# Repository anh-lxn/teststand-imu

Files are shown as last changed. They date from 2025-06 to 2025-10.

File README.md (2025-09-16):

# IMU Calibration Test Stand with Differential Gear System

## Project Overview

This project presents the design and function of a **two-axis IMU calibration test stand**, developed to calibrate inertial measurement units (IMUs) such as the [MPU6050](https://invensense.tdk.com/products/motion-tracking/6-axis/mpu-6050/). The test stand enables controlled, repeatable motion for precise sensor calibration.

All mechanical parts are **3D printed**, and motion is driven by **NEMA 17 stepper motors** in combination with an **HTD timing belt system**. The movement is realized through a **differential gear mechanism**, providing two degrees of freedom (DoF).

---

## ⚙️ System Characteristics

- 🎯 **Purpose**: Accurate calibration of IMUs
- 🧩 **Mechanics**: Differential gear-driven motion
- 🖨️ Manufacturing: Fully 3D printed components
- 🔄 **Degrees of Freedom**:  
  - **Z-axis**: Independently rotatable  
  - **X and Y axes**: Coupled motion, dependent on Z-axis rotation
- 🚀 **Actuation**: NEMA 17 stepper motors with HTD belt drive
- 🧠 **Controller**: Arduino Nano for motor control and signal processing

---

## 🖼️ Visualizations

<b>Z-Axis Rotation</b> &nbsp;&nbsp;&nbsp;&nbsp;&nbsp;&nbsp;&nbsp;&nbsp;&nbsp;&nbsp;&nbsp;&nbsp;&nbsp;&nbsp;&nbsp;&nbsp;&nbsp;&nbsp;&nbsp;&nbsp;&nbsp;&nbsp;&nbsp;&nbsp;&nbsp;&nbsp;&nbsp;&nbsp;&nbsp;&nbsp;&nbsp;&nbsp;&nbsp;&nbsp;&nbsp;&nbsp;&nbsp;&nbsp;&nbsp;&nbsp;&nbsp;&nbsp;&nbsp;&nbsp;&nbsp;&nbsp;&nbsp;&nbsp;&nbsp;&nbsp;&nbsp;&nbsp;&nbsp;&nbsp;&nbsp;&nbsp;&nbsp;&nbsp;&nbsp;&nbsp;&nbsp;&nbsp;&nbsp;&nbsp;&nbsp;&nbsp;&nbsp;&nbsp;&nbsp;&nbsp;&nbsp;&nbsp;&nbsp;&nbsp;&nbsp;&nbsp;&nbsp; <b>X/Y-Axis Rotation</b><br>
 

<b>Exploded Assembly View</b><br>
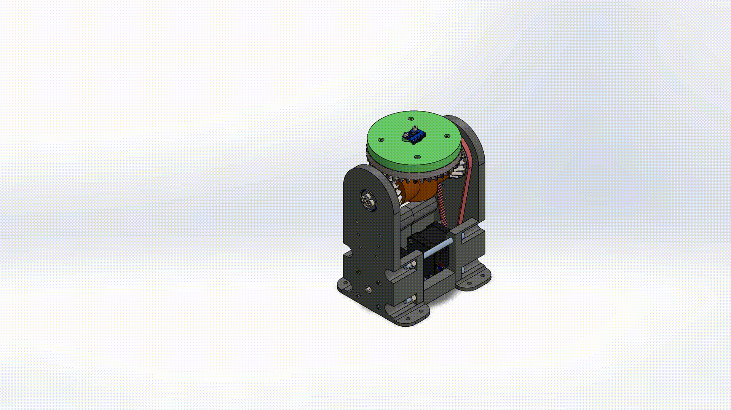
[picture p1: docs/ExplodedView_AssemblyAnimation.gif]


---

## 🛠️ Calibration in Real Life (HAS TO BE ADDED!!!)

<p align="center">
  
</p>

This animation demonstrates the real-life calibration process, where the IMU undergoes controlled multi-axis rotations.  
It shows how the test stand executes repeatable motion sequences to allow for accurate sensor calibration.

---
## Wiring Diagram

<p align="center">
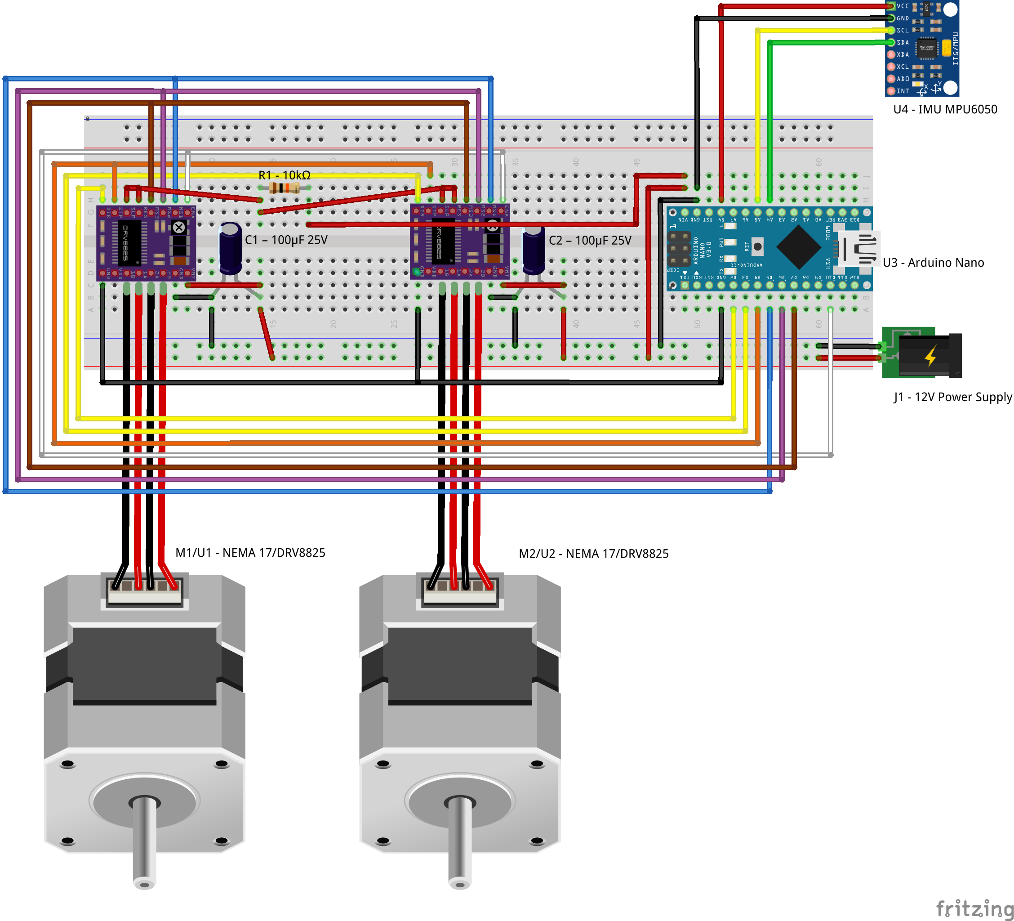
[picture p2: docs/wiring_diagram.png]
  
</p>

The wiring diagram shows the connection between the Arduino Nano, stepper motor drivers (A4988/DRV8825), NEMA 17 stepper motors, the MPU6050 sensor, and power supply.

---

## 📊 Sensor Data Visualization

To validate the calibration process, both **accelerometer** and **gyroscope** signals were recorded before and after calibration.  
The plots show the comparison between **raw data**, **calibrated data**, and the **expected values** during controlled rotations.  

### 📈 Accelerometer Calibration
<p align="center">
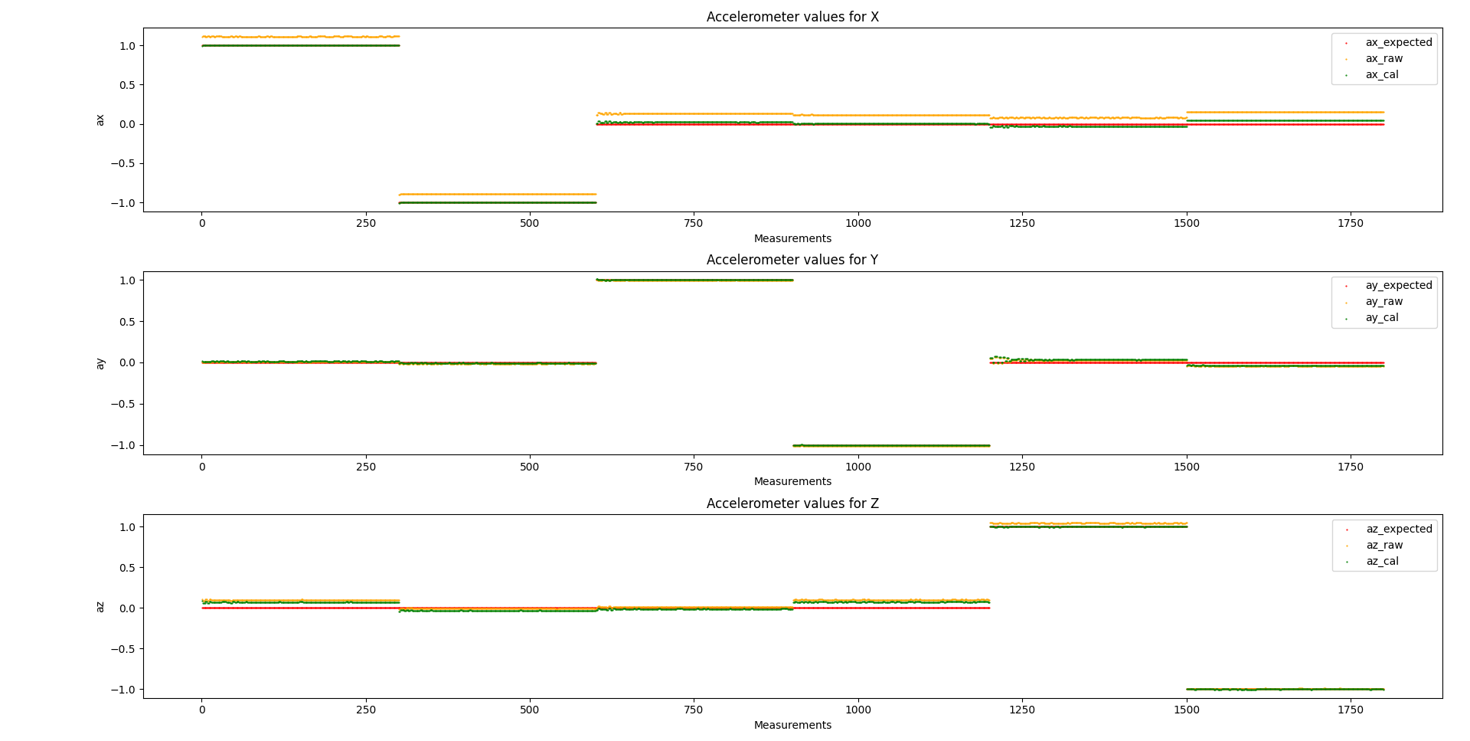
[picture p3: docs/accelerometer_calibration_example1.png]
  
</p>

The accelerometer plots illustrate the three axes (**ax, ay, az**).  
- 🟠 *Raw data* (uncalibrated)  
- 🟢 *Calibrated data* (after bias and scale factor correction)  
- 🔴 *Expected values* (reference for controlled rotation)  

Calibration significantly reduces **bias** and aligns the output closer to the expected reference.  

---

### 📈 Gyroscope Calibration
<p align="center">
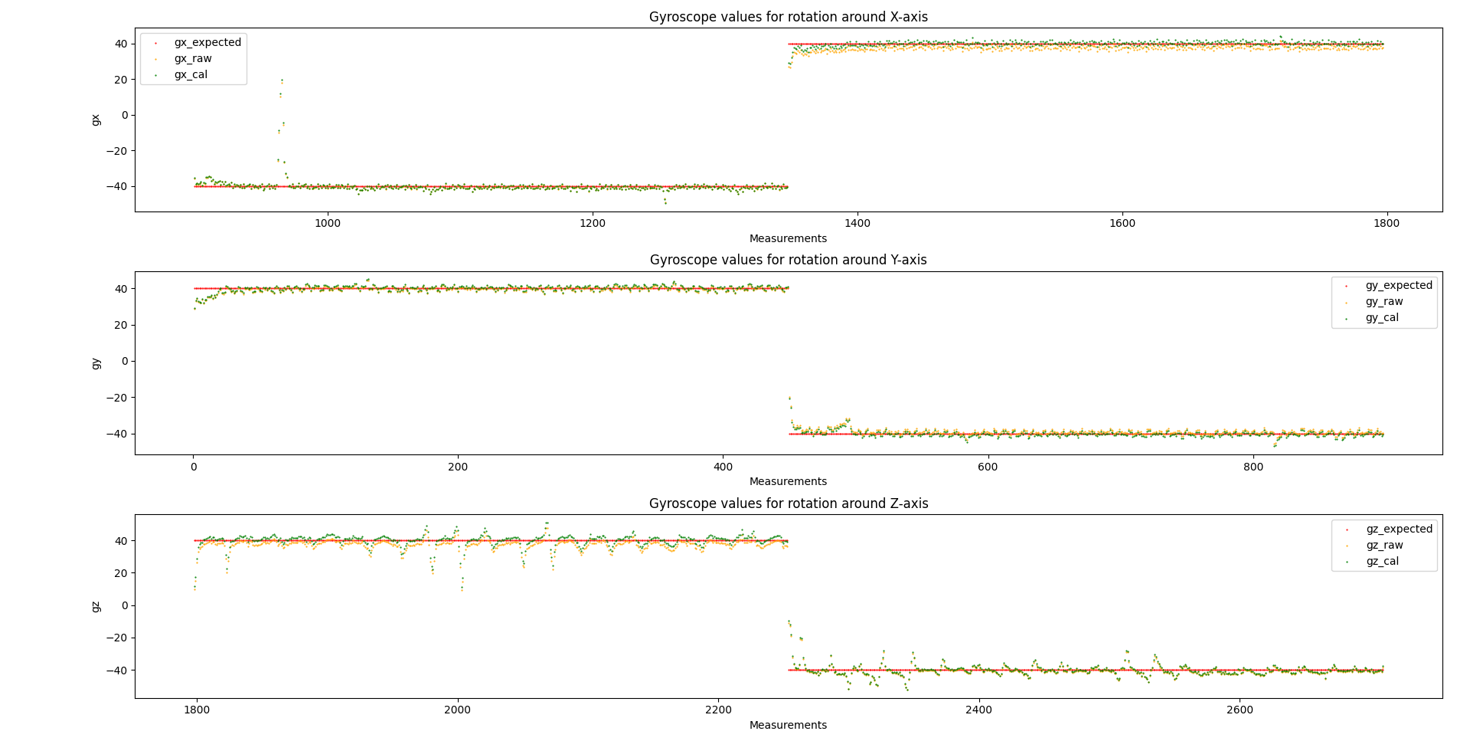
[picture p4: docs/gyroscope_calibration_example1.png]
  
</p>

The gyroscope plots illustrate the three axes (**gx, gy, gz**).  
- 🟠 *Raw data* (uncalibrated)  
- 🟢 *Calibrated data* (after correction)  
- 🔴 *Expected values* (reference for applied rotation)  

Calibration minimizes **offset drift** and ensures a more accurate representation of angular velocity.  

---

✅ These visualizations confirm that the test stand enables **reliable calibration** by applying repeatable motion sequences and comparing sensor output to ground truth.

## 🧠 Motivation

Reliable IMU data is only possible when the sensors are properly **calibrated**. This test stand allows for controlled motion sequences, helping to identify and compensate for common issues such as drift, offset, and axis misalignment.

---

## 🚀 Project Status & Outlook

✅ The hardware and mechanics of the calibration test stand are complete.
🔜 Future work will focus on:

- 📈 Further data processing
- 💻 Graphical user interface (GUI) for easy operation

---

## 👨‍🔧 Author

- Anh Le Xuan – Student Assistant (SHK), responsible for mechanical design and implementation  
- Benjamin Waschilewski – Research Associate and Supervisor  
- Institute of Textile Machinery and High Performance Material Technology (ITM), TU Dresden

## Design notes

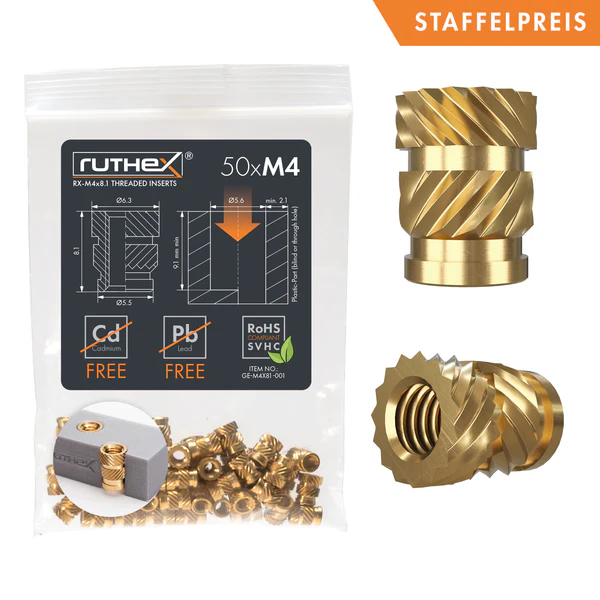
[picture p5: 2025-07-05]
docs/M4x6.3x8.1(M4xDxL).jpg

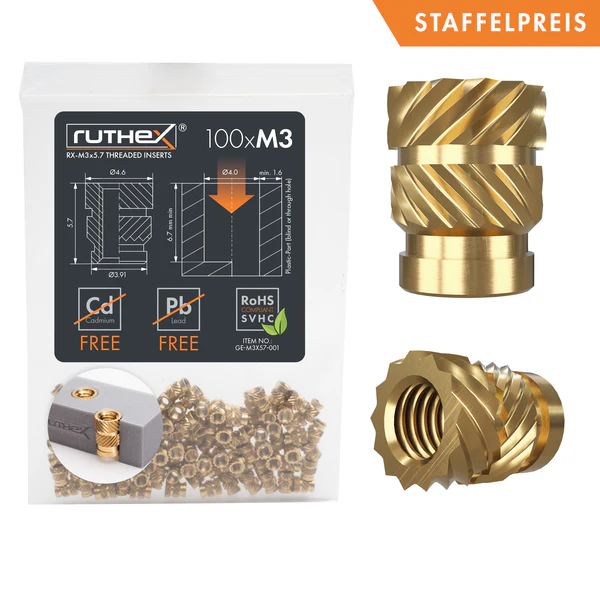
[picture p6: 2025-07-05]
docs/M3x4.6x5.7(M3xDxL).jpg

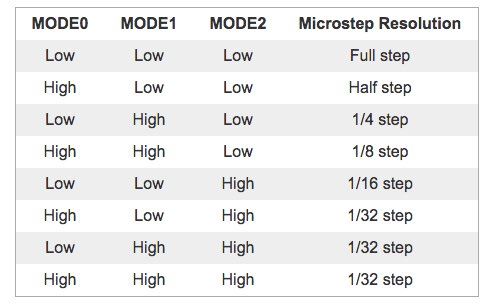
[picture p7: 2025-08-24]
docs/DRV8825_MicrosteppingModes.jpeg

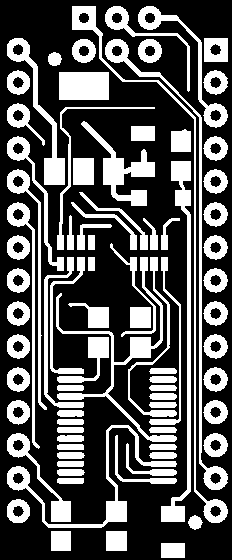
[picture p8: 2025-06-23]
cad/Version_2_neu(Differentialgetriebe)/Elektronik/arduino nano/nanobot_maskm.bmp

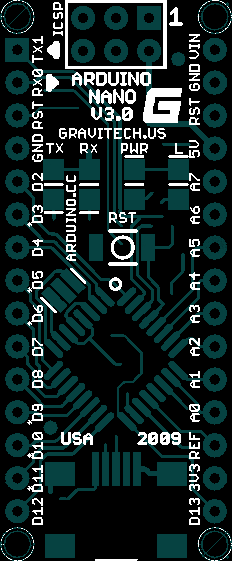
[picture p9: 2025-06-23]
cad/Version_2_neu(Differentialgetriebe)/Elektronik/arduino nano/nanoblack.bmp

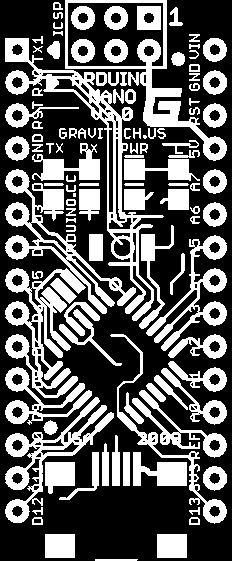
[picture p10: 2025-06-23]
cad/Version_2_neu(Differentialgetriebe)/Elektronik/arduino nano/nanoblack_mask.bmp

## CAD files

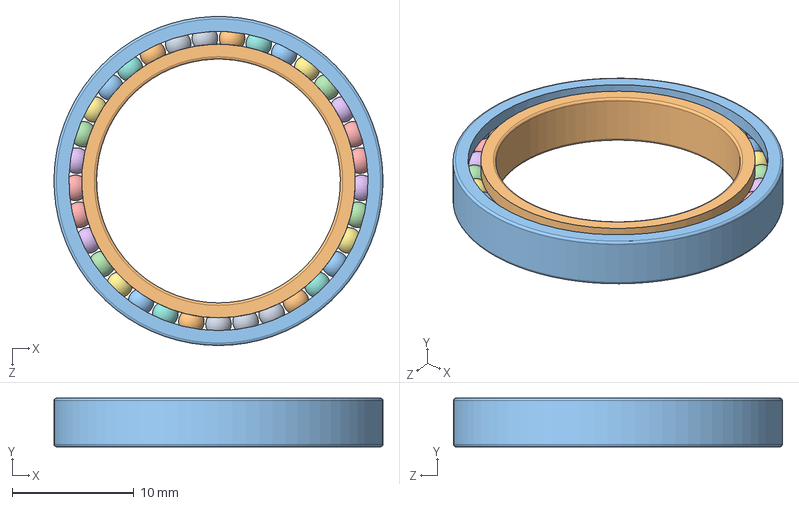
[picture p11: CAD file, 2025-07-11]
cad/Version_2_neu(Differentialgetriebe)/Radialrillenkugellager 6704 20x27x4/Radialrillenkugellager 6704 20x27x4.SLDASM
27.0 x 4.00 x 27.0 mm

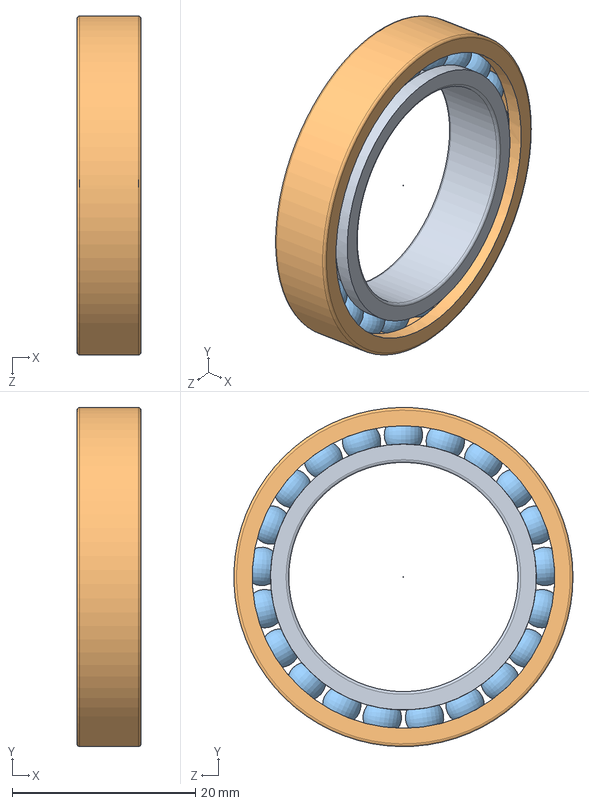
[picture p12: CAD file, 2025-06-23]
cad/Version_2_neu(Differentialgetriebe)/Kegelrad/Radialrillenkugellager 6805 25x37x7/Radialrillenkugellager 6805 25x37x7.SLDASM
7.00 x 37.0 x 37.0 mm
bearing_6805_01
bearing_6805_02
bearing_6805_03

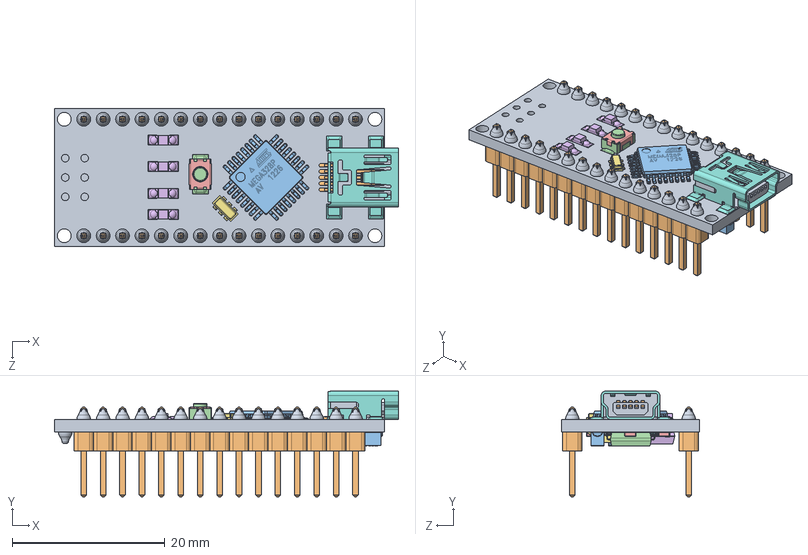
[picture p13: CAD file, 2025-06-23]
cad/Version_2_neu(Differentialgetriebe)/Pack and Go/arduino nano.SLDASM
45.0 x 13.9 x 18.0 mm
nano-board
15pin_header__ x 2
atmega328
ftdi FT232rl
smt_resistor222 x 5
led x 4
16mhz crystal - measured
MINIUSBSHELL
MINIUSBCORE
MINI USB CONTACT x 5
cap106C x 2
reset core
reset shell
nano - reg
NANO DIODE
189 RESISTOR PACK
102 RESISTOR PACK

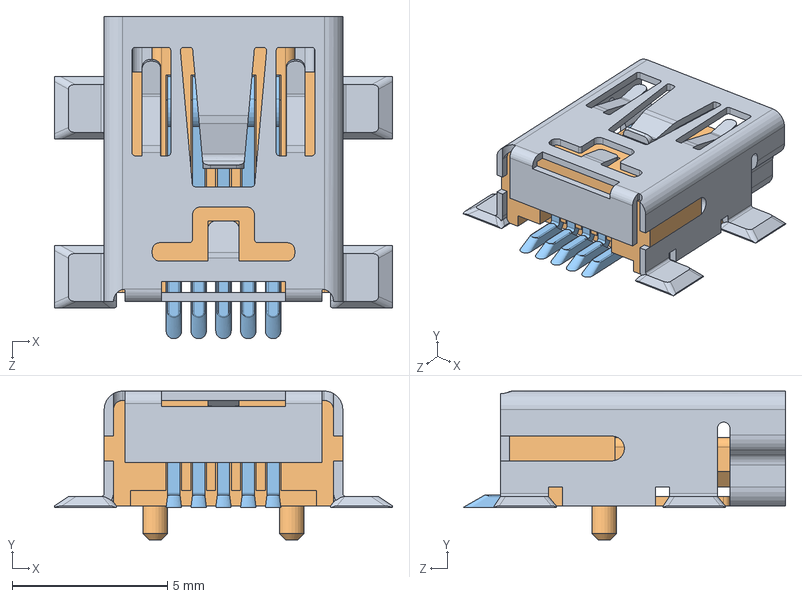
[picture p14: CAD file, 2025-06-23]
cad/Version_2_neu(Differentialgetriebe)/Pack and Go/MINIUSB - MEASURED.SLDASM
10.9 x 4.80 x 10.4 mm
MINIUSBSHELL
MINIUSBCORE
MINI USB CONTACT x 5

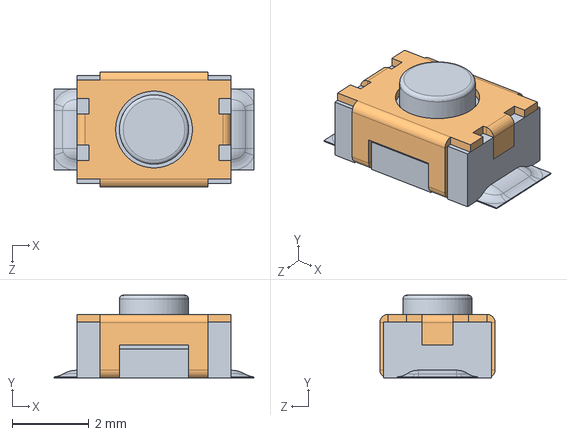
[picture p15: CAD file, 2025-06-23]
cad/Version_2_neu(Differentialgetriebe)/Pack and Go/reset button.SLDASM
5.20 x 2.15 x 3.00 mm
reset core
reset shell

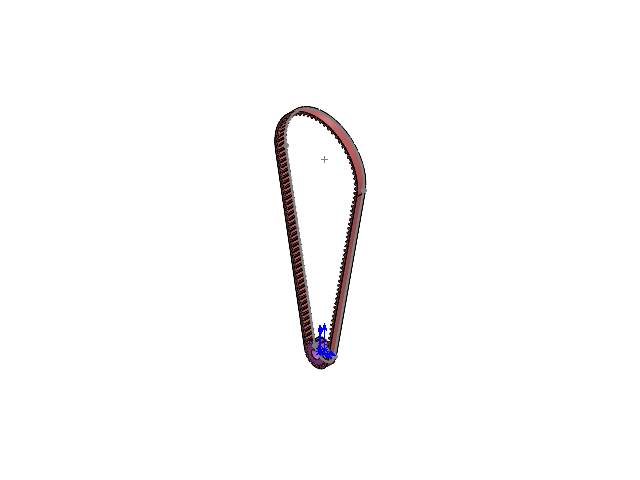
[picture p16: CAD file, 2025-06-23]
cad/Version_2_neu(Differentialgetriebe)/Motorantrieb/Motorantrieb.SLDASM
Motorantrieb_Zahnriemen
Riemen3-4

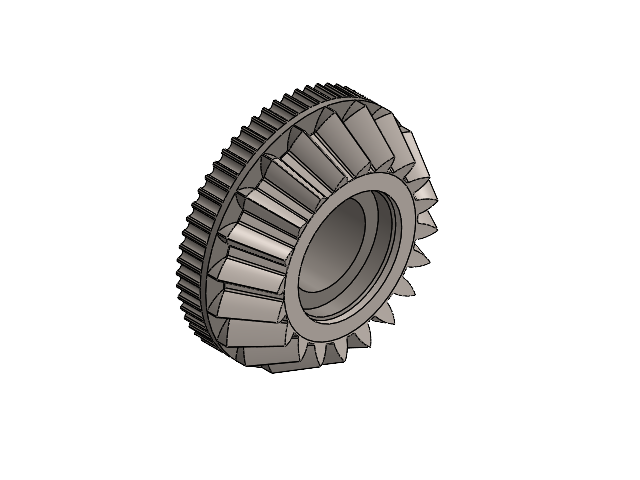
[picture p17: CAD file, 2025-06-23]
cad/Version_2_neu(Differentialgetriebe)/Pack and Go/Ritzel.SLDASM
Zahnraderweiterung
straight bevel pinion_iso

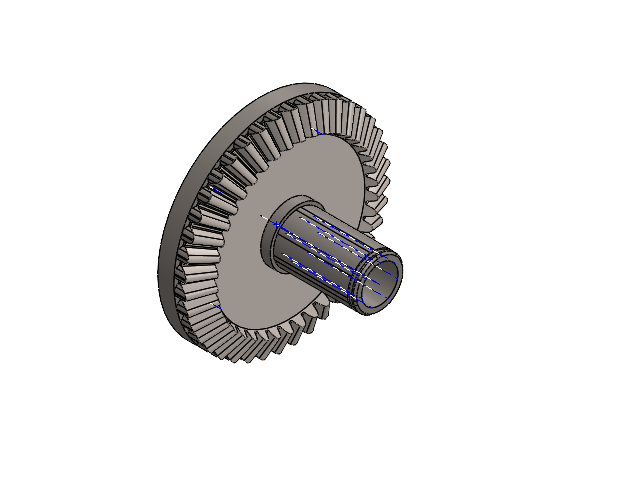
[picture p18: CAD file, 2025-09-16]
cad/Version_2_neu(Differentialgetriebe)/Kegelrad/Kegelrad.SLDASM
Kegelrad_Custom
Zahnraderweiterung Kegelrad

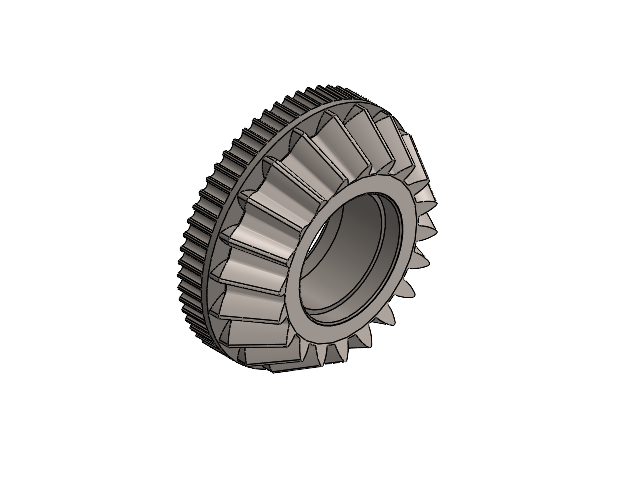
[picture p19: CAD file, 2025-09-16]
cad/Version_2_neu(Differentialgetriebe)/Ritzel/Ritzel.SLDASM
Zahnraderweiterung
Ritzel_Custom

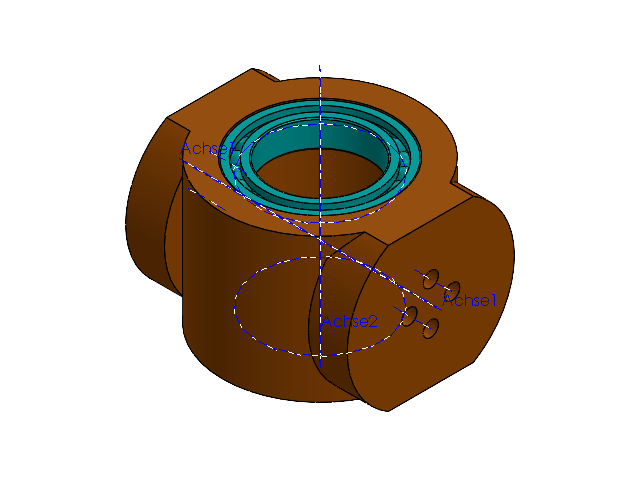
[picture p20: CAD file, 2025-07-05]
cad/Version_2_neu(Differentialgetriebe)/Kegelrad/Getriebehub_Baugruppe.SLDASM
Getriebehub
bearing_6805_01 x 2
bearing_6805_02 x 2
bearing_6805_03 x 2

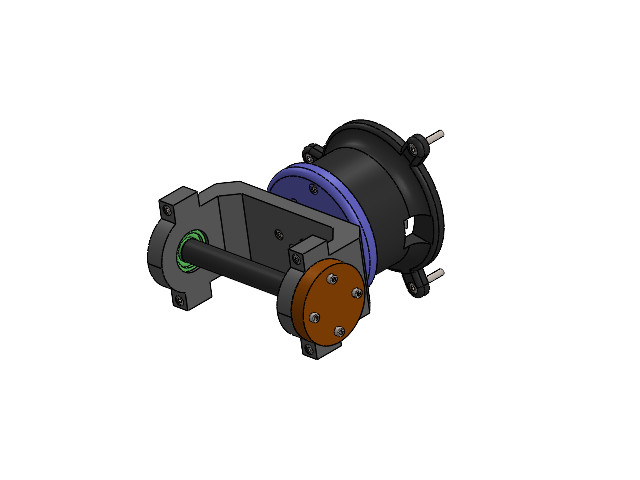
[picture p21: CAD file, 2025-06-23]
cad/Version_1_alt/IMU-Teststand.SLDASM
Schrittmotor z-Achse
socket head cap screw 4762_din x 14
Unteres Gehäuse
Gewindeeinsatz M3xL4xD4 x 7
Deckel für unteres Gehäuse
radial ball bearing_68_din x 3
Welle
circlip for shafts normal_din x 2
Deckel Festlager
Gewindeeinsatz M3xL6xD4 x 4
socket head cap screw_iso x 8
U-förmiger Gimbal Rahmen - Unteres Teil
Verbindung Motor mit U-Gimbal
hex nut style 1 gradeab_iso x 4

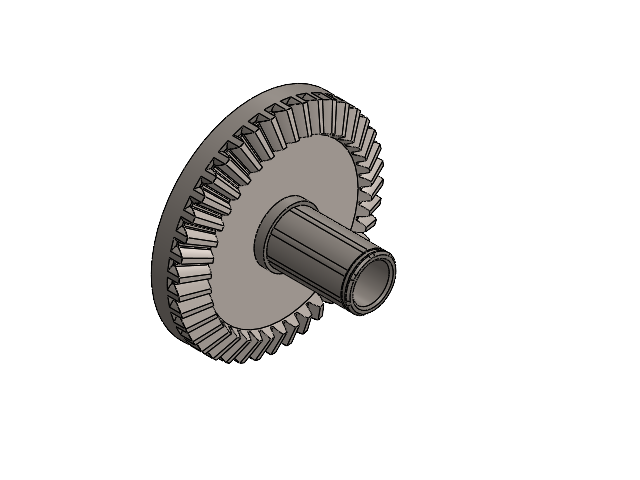
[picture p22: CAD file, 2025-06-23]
cad/Version_2_neu(Differentialgetriebe)/Pack and Go/Kegelrad.SLDASM
straight bevel gear_iso
Zahnraderweiterung Kegelrad

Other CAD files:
cad/Version_2_neu(Differentialgetriebe)/Pack and Go/Getriebehub_Baugruppe.SLDASM
cad/Version_2_neu(Differentialgetriebe)/Pack and Go/Radialrillenkugellager 6704 20x27x4.SLDASM
cad/Version_2_neu(Differentialgetriebe)/Pack and Go/Radialrillenkugellager 6805 25x37x7.SLDASM
cad/Version_2_neu(Differentialgetriebe)/Elektronik/arduino nano/MINIUSB - MEASURED.SLDASM
cad/Version_2_neu(Differentialgetriebe)/Elektronik/arduino nano/reset button.SLDASM
cad/Version_2_neu(Differentialgetriebe)/Elektronik/arduino nano/arduino nano.SLDASM
cad/Version_1_alt/Deckel Festlager.SLDPRT
cad/Version_1_alt/Deckel für unteres Gehäuse.SLDPRT
cad/Version_1_alt/Gewindeeinsatz M3xL4xD4.SLDPRT
cad/Version_1_alt/Gewindeeinsatz M3xL6xD4.SLDPRT
cad/Version_1_alt/Kugellager Deckel DIN 625 - 6000.SLDPRT
cad/Version_1_alt/Motoren/Schrittmotor z-Achse.SLDPRT
cad/Version_1_alt/U-förmiger Gimbal Rahmen - Oberes Teil.SLDPRT
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

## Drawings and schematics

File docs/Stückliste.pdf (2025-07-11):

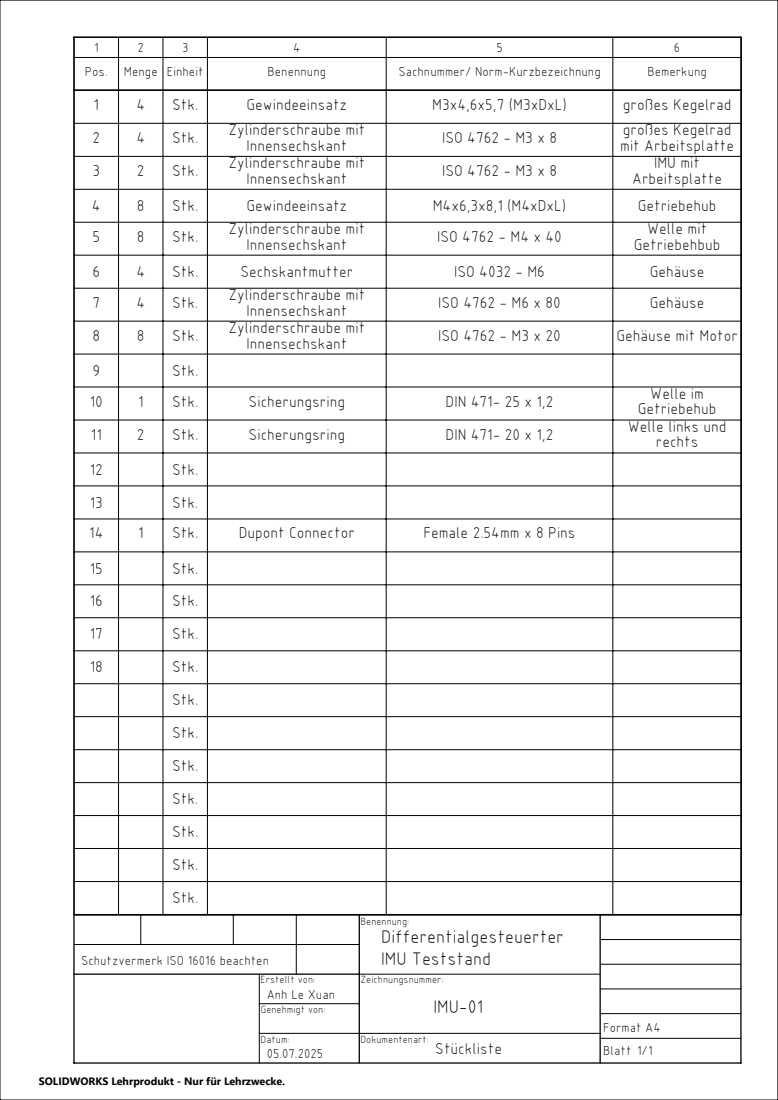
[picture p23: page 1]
Pos. Menge Einheit; Benennung; Sachnummer/ Norm-Kurzbezeichnung; Bemerkung; Stk.; Gewindeeinsatz; M3x4,6x5,7 (M3xDxL); großes Kegelrad; Zylinderschraube mit; Innensechskant; ISO 4762 - M3 x 8; mit Arbeitsplatte; IMU mit; M4x6,3x8,1 (M4xDxL); Getriebehub; ISO 4762 - M4 x 40; Welle mit; Sechskantmutter; ISO 4032 - M6; Gehäuse; ISO 4762 - M6 x 80; ISO 4762 - M3 x 20; Gehäuse mit Motor; Sicherungsring; DIN 471- 25 x 1,2; Welle im; DIN 471- 20 x 1,2; Welle links und; Dupont Connector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

Benennung: Differentialgesteuerter IMU Teststand

Schutzvermerk ISO 16016 beachten

Erstellt von: Anh Le Xuan | Zeichnungsnummer: IMU-01

SOLIDWORKS Lehrprodukt - Nur für Lehrzwecke.

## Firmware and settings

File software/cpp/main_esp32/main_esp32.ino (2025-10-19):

#include <Arduino.h>
#include <AccelStepper.h>
#include <Wire.h>

//
// ==========================================================
//                ESP32 Dual-Core Stepper + IMU
// ==========================================================
//  - Core 0: IMU-Lesen über I²C (MPU6050)
//  - Core 1: Motorsteuerung mit AccelStepper
//
//  Autor: Anh Le Xuan
//  Version: Final Cleaned & Documented
// ==========================================================
//

// ------------------- FreeRTOS Threads -------------------
TaskHandle_t MotorTaskHandle;
TaskHandle_t ImuTaskHandle;

// ------------------- Globale Zustände -------------------
bool motorEnabled = false;
volatile bool motorDone = false;
int transitionSpeed = 10000;      // Max. Drehgeschwindigkeit für Übergänge
float dwellTime = 0.05;           // Stillstandszeit an Messposition (s)
int numPositions = 10;            // Anzahl Messpositionen pro Umdrehung
float degreePerStep = 60.0;       // Rotationswinkel pro Z-Schritt (°)
int rotationCount = 0;            // Zählt Anzahl Übergänge
float motorAcceleration = 20000.0; // Beschleunigung (Steps/s²)
const unsigned long startupDelayMs = 3000; // Wartezeit nach Start
unsigned long startTime;

// ------------------- Motor-Pins -------------------
#define DIR_PIN_1 26
#define DIR_PIN_2 23
#define STEP_PIN 25
#define ENABLE_PIN 33
#define M0_PIN 14
#define M1_PIN 27
#define M2_PIN 32

// ------------------- Kinematik -------------------
const float teethBelt = 15.0f;
const float teethPulley = 59.0f;
const float gearRatio = (teethPulley / teethBelt) / 2.0; // mechanische Übersetzung
const float fullStepsPerRev = 200;
int microstepping = 16;  // 1/16 Microstep
float microStepsPerRev = fullStepsPerRev * microstepping;

// Stepper-Objekt (beide Motoren synchron über ein STEP-Signal)
AccelStepper dualStepper(AccelStepper::DRIVER, STEP_PIN, 13);

// ==========================================================
//                     Hilfsfunktionen
// ==========================================================

// Berechnet Mikroschritte pro Sekunde aus gewünschter Winkelgeschwindigkeit (°/s)
float calcMicrostepsPerSecond(float angularVelocityDegPerSec) {
  float motorAngularVelocity = angularVelocityDegPerSec * gearRatio;
  float revolutionsPerSec = motorAngularVelocity / 360.0;
  return revolutionsPerSec * microStepsPerRev;
}

// Berechnet Mikroschritte aus gewünschtem Drehwinkel (in Umdrehungsanteilen)
float calcMicrostepsPerRotation(float rotations) {
  return rotations * microStepsPerRev * gearRatio;
}

// ==========================================================
//                   Motor-Setup
// ==========================================================
void setupMotorPins() {
  pinMode(STEP_PIN, OUTPUT);
  pinMode(DIR_PIN_1, OUTPUT);
  pinMode(DIR_PIN_2, OUTPUT);
  pinMode(M0_PIN, OUTPUT);
  pinMode(M1_PIN, OUTPUT);
  pinMode(M2_PIN, OUTPUT);
  pinMode(ENABLE_PIN, OUTPUT);

  // Microstepping auf 1/16 konfigurieren
  digitalWrite(M0_PIN, HIGH);
  digitalWrite(M1_PIN, HIGH);
  digitalWrite(M2_PIN, LOW);

  // Motor initial deaktivieren
  digitalWrite(ENABLE_PIN, HIGH);

  // Stepper konfigurieren
  dualStepper.setMinPulseWidth(5);
  dualStepper.setAcceleration(motorAcceleration);
  dualStepper.setCurrentPosition(0);

  startTime = millis();
}

// Motor aktivieren/deaktivieren
void enableMotor()  { digitalWrite(ENABLE_PIN, LOW); }
void disableMotor() { digitalWrite(ENABLE_PIN, HIGH); }

// ==========================================================
//           Bewegung: Stillstands- und Übergangsphasen
// ==========================================================

// Fährt n Stillstandspositionen mit definiertem Pausenintervall ab
void moveToMeasurementPositions(int numPositions, bool dir1High, bool dir2High) {
  float deg = 360.0 / numPositions;
  float rotations = deg / 360.0;
  float angularSpeed = deg / dwellTime;

  dualStepper.setMaxSpeed(calcMicrostepsPerSecond(angularSpeed));

  for (int i = 0; i < numPositions; i++) {
    // Stillstand (Messung)
    vTaskDelay(dwellTime * 1000 / portTICK_PERIOD_MS);

    // Richtung setzen
    digitalWrite(DIR_PIN_1, dir1High ? HIGH : LOW);
    digitalWrite(DIR_PIN_2, dir2High ? HIGH : LOW);

    // Zielposition berechnen
    long target = dualStepper.currentPosition() + calcMicrostepsPerRotation(rotations);
    dualStepper.moveTo(target);

    // Bewegung ausführen
    while (dualStepper.distanceToGo() != 0) {
      dualStepper.run();
    }
  }
}

// Dreht nach jeder Messrunde um einen festen Winkel (z. B. 60°)
void transitionZ(bool dir1High, bool dir2High) {
  dualStepper.setMaxSpeed(transitionSpeed);

  digitalWrite(DIR_PIN_1, dir1High ? HIGH : LOW);
  digitalWrite(DIR_PIN_2, dir2High ? HIGH : LOW);

  float rotation = (degreePerStep / 360.0) * 2.0; // *2 wegen Übersetzung
  long target = dualStepper.currentPosition() + calcMicrostepsPerRotation(rotation);
  dualStepper.moveTo(target);

  while (dualStepper.distanceToGo() != 0) {
    dualStepper.run();
  }

  rotationCount++;
}

// Führt eine größere Gesamtrotation durch (z. B. Heimfahrt)
void transitionFull(float rotation, bool dir1High, bool dir2High) {
  dualStepper.setMaxSpeed(transitionSpeed);
  digitalWrite(DIR_PIN_1, dir1High ? HIGH : LOW);
  digitalWrite(DIR_PIN_2, dir2High ? HIGH : LOW);

  long target = dualStepper.currentPosition() + calcMicrostepsPerRotation(rotation);
  dualStepper.moveTo(target);

  while (dualStepper.distanceToGo() != 0) {
    dualStepper.run();
  }
}

// ==========================================================
//                       MPU6050
// ==========================================================
const uint8_t MPU = 0x68;
const float g0 = 9.81;
const float accScale = g0 / 16384.0;
const float gyroScale = 131.0 / (PI / 180.0); // rad/s

void writeMPU(uint8_t reg, uint8_t val) {
  Wire.beginTransmission(MPU);
  Wire.write(reg);
  Wire.write(val);
  Wire.endTransmission(true);
}

void setupMPU(uint16_t sampleRateHz = 100) {
  writeMPU(0x6B, 0x01); // PWR_MGMT_1
  writeMPU(0x6C, 0x00); // PWR_MGMT_2
  writeMPU(0x1B, 0x00); // GYRO_CONFIG
  writeMPU(0x1C, 0x00); // ACCEL_CONFIG
  writeMPU(0x1A, 0x04); // DLPF
  uint8_t div = (uint8_t)(1000 / sampleRateHz - 1);
  writeMPU(0x19, div);
  writeMPU(0x6A, 0x04); // FIFO Reset
}

// Liest aktuelle Sensordaten und gibt sie über Serial aus
void readIMUData() {
  Wire.beginTransmission(MPU);
  Wire.write(0x3B);
  Wire.endTransmission(false);
  Wire.requestFrom(MPU, 14, true);

  if (Wire.available() == 14) {
    int16_t ax = (Wire.read() << 8) | Wire.read();
    int16_t ay = (Wire.read() << 8) | Wire.read();
    int16_t az = (Wire.read() << 8) | Wire.read();
    Wire.read(); Wire.read(); // Temp überspringen
    int16_t gx = (Wire.read() << 8) | Wire.read();
    int16_t gy = (Wire.read() << 8) | Wire.read();
    int16_t gz = (Wire.read() << 8) | Wire.read();

    Serial.printf("%.5f,%.5f,%.5f,%.5f,%.5f,%.5f\n",
                  ax * accScale, ay * accScale, az * accScale,
                  gx / gyroScale, gy / gyroScale, gz / gyroScale);
  }
}

// ==========================================================
//                     Tasks (Threads)
// ==========================================================

// Task 1: IMU-Daten lesen (Core 0)
void TaskReadIMU(void *pvParameters) {
  for (;;) {
    if (!motorDone) {
      readIMUData();
      vTaskDelay(10 / portTICK_PERIOD_MS); // 100 Hz
    } else {
      vTaskDelay(100 / portTICK_PERIOD_MS);
    }
  }
}

// Task 2: Motorsteuerung (Core 1)
void TaskMotor(void *pvParameters) {
  motorDone = false;

  for (;;) {
    // Wartephase beim Start
    if (!motorEnabled) {
      if (millis() - startTime >= startupDelayMs) {
        enableMotor();
        motorEnabled = true;
      } else {
        vTaskDelay(10 / portTICK_PERIOD_MS);
        continue;
      }
    }

    // Bewegungslogik (abwechselnde Drehrichtungen)
    if (rotationCount % 2 == 0) {
      moveToMeasurementPositions(numPositions, HIGH, LOW);
      transitionZ(HIGH, HIGH);
    } else {
      moveToMeasurementPositions(numPositions, LOW, HIGH);
      transitionZ(HIGH, HIGH);
    }

    // Nach kompletter 360°-Drehung: Motor deaktivieren
    if (rotationCount >= (int)(360.0 / degreePerStep)) {
      transitionFull(2.0, LOW, LOW);
      disableMotor();
      motorDone = true;
      Serial.println("✅ Motorlauf abgeschlossen");
      vTaskDelete(NULL);
    }

    vTaskDelay(1 / portTICK_PERIOD_MS);
  }
}

// ==========================================================
//                         Setup
// ==========================================================
void setup() {
  Serial.begin(115200);
  Serial.println("\n=== ESP32 Dual-Core Motor + IMU gestartet ===");

  setupMotorPins();
  Wire.begin(21, 22);
  Wire.setClock(400000);
  setupMPU();
  delay(100);

  // Core-Zuweisung: IMU -> Core 0, Motor -> Core 1
  xTaskCreatePinnedToCore(TaskReadIMU, "IMU_Task", 8192, NULL, 2, &ImuTaskHandle, 0);
  xTaskCreatePinnedToCore(TaskMotor,  "Motor_Task", 8192, NULL, 2, &MotorTaskHandle, 1);
}

void loop() {
  // Alle Aktionen laufen in Tasks
}

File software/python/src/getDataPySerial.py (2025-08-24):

import os
import sys
import serial
import pandas as pd

# === Pfade ===
# os.path.abspath(__file__)      → absoluter Pfad zur Datei
# os.path.dirname(path)          → Verzeichnisname vom Pfad
# os.path.join(a, b, ...)        → Pfade zusammenbauen

BASE_DIR = os.path.dirname(os.path.abspath(__file__)) # aktueller Ordner
GIT_DIR = os.path.abspath(os.path.join(BASE_DIR, "..", "..", "..")) # teststand-imu Ordner
DATA_DIR = os.path.join(GIT_DIR, "data") # data Ordner
CSV_ACCEL = os.path.join(DATA_DIR, "imu_accel_data.csv") # CSV für Accel-Daten
CSV_GYRO = os.path.join(DATA_DIR, "imu_gyro_data.csv") # CSV für Gyro-Daten


# === Einstellungen anpassen ===
PORT = "COM4"
BAUDRATE = 115200

# === Verbindung herstellen ===
ser = serial.Serial(PORT, BAUDRATE, timeout=1) # IDE Code wird nochmal ausgeführt

print("Fange an Daten zu sammeln...")

# Leere Daten Listen
data_accel = []
data_gyro = []

#=== Accel-Daten sammeln ===
while True:
    try:
        line = ser.readline().decode("utf-8").strip() # Lese die Serial
        if not line: # Wenn keine Daten, nächste Iteration
            continue
        # Header-Zeile überspringen
        if line.startswith("id"):  
            continue
        
        parts = line.split(",")
        
        if not "," in line:
            print(line)

        # Accel Data
        if len(parts) == 8:
            id, i, ax, ay, az, gx, gy, gz = parts
            data_accel.append([id, int(i),int(ax), int(ay), int(az), int(gx), int(gy), int(gz)])
        
        
        # Gyro Data
        if len(parts) == 6:
            id, i, axis, gyro_raw, gyro_dps, w = parts
            data_gyro.append([id, i, axis, gyro_raw, gyro_dps, w])

        # Messung Stoppen
        if line == "CALIBRATION DONE":
            break

    except KeyboardInterrupt:
        print("Manuell gestoppt")
        break

ser.close()

# === In DataFrame speichern ===
# Accel Data
df_accel = pd.DataFrame(data_accel, columns=["id","i","ax","ay","az","gx","gy","gz"])
df_accel.to_csv(CSV_ACCEL, index= False)
# Gyro Data
df_gyro = pd.DataFrame(data_gyro, columns=["id","i","axis","gyro_raw", "gyro_dps", "w"])
df_gyro.to_csv(CSV_GYRO, index = False)

print(f"{len(df_accel)} Zeilen gespeichert in {CSV_ACCEL}")
print(f"{len(df_gyro)} Zeilen gespeichert in {CSV_GYRO}")

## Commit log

2025-06-06 Konstruktion unteres Teil fertig, oberes Teil muss weiter gemacht werden insbesondere Welle und Befestigung Schrittmotor
    [Deckel für unteres Gehäuse.SLDPRT, Einkaufsliste.xlsx, Gewindeeinsatz M3xL4xD4.SLDPRT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]
2025-07-05 fast druckfertig
    [2x Gehäuse (Stützstruktur notwendig).STL, 2x Motorantrieb_Zahnriemen.STL, 2x Ritzel.STL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]
2025-07-11 stueckliste updated und als pdf
    [Stückliste.SLDDRW]
2025-07-11 updated Ritzel und Welle
    [2x Ritzel und 2x Welle.3mf, 2x Ritzel.STL, 2x Zahnriemen_Welle.STL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]
2025-08-24 alles fertig außer datenverarbeitung
    [2x Motorantrieb_Zahnriemen.STL, 2x Ritzel.STL, 2x Zahnriemen_Welle.STL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]
2025-08-25 grobe Datenauswertung für Kalibirierung fertig
    [imu_accel_data.csv, imu_gyro_data.csv]
2025-09-16 wiring diagram done, kegelrad und ritzel toleranzen angepasst, docs hinzugefügt
    [2x Ritzel_angepasst (Stützstruktur notwendig).STL, Kegelrad.SLDASM, Kegelrad_Custom.SLDPRT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]
2025-10-19 adding files to main branch
    [data.csv, imu_accel_data.csv, imu_gyro_data.csv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]
2025-10-19 esp32 kommunikation funktioniert
2025-10-19 esp32 mit imu und drv8825 fertig, code ist gecleant und kommentiert
